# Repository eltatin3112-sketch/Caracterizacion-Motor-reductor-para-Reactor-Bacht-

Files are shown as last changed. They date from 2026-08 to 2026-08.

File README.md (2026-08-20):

# CARACTERIZACIÓN DINÁMICA Y ELÉCTRICA DEL MOTORREDUCTOR (AGITADOR) - GRUPO 5
## Identificación Experimental de Mezcla - Sistemas de Control II (UNET)

Elaborado por: Daniel Torres y Yermey Castro

---

### 1. OBJETIVO DEL PROYECTO DE CARACTERIZACIÓN
Este repositorio contiene todo lo necesario para reproducir la caracterización física de un motorreductor DC utilizado como agitador en un Reactor Batch. 

En la industria, no podemos controlar lo que no conocemos. Por ello, el objetivo de esta práctica es medir cómo responde el motor ante diferentes niveles de potencia (PWM) bajo la resistencia viscosa de 2 Litros de agua. Los datos extraídos permiten identificar no linealidades (como la **Zona Muerta** y la **Saturación**), lo cual es un paso fundamental en *Sistemas de Control II* antes de diseñar un lazo cerrado.

---

### 2. LISTADO DE COMPONENTES UTILIZADOS y Hardware Mínimo Requerido
Para reproducir este experimento, se requiere el siguiente hardware. Todos los componentes deben compartir una referencia de tierra común (GND).

| Componente | Referencia / Modelo | Cantidad | Función en el sistema |
| :--- | :--- | :--- | :--- |
| **Microcontrolador** | ESP32 DevKit V1 (30 pines) | 1 | Procesamiento, conteo de interrupciones y servidor Web WiFi. |
| **Driver de Motor** | Puente H L298N | 1 | Etapa de potencia para suministrar 12V al motor modulados por PWM. |
| **Actuador** | Motorreductor DC tipo TT | 1 | Agitador mecánico del reactor. |
| **Sensor (Feedback)**| Encoder Óptico FC-03 | 1 | Lectura de las ranuras del disco para calcular RPM reales. |
| **Fuente de Poder** | Fuente ATX de PC (Reciclada)| 1 | Suministra 12V estables (Cable amarillo) para la potencia. |
| **Carga de Trabajo** | Jarra plástica + Agua | 1 | Simula la inercia viscosa con 2 Litros de agua. |
| **Aspas** | Fabricadas con alambre y aspas de ventiladores de 12V | 2 | 1 Aspa ligera y 1 Aspa pesada para comparar torque resistente. |

---

### 3. TABLA DE CONEXIONES Y PINOUT (CABLEADO)
Para garantizar el correcto funcionamiento de las señales de control de alta velocidad (PWM e interrupciones del encoder) y mitigar el ruido, se unificaron las referencias de tierra del sistema. Las conexiones del módulo ESP32, el driver de motores y el sensor se estructuran de la siguiente manera:

| Conexión Origen | Señal / Pin | Destino Hardware | Notas Técnicas |
| :--- | :--- | :--- | :--- |
| **Fuente ATX** | `+12V` (Cable Amarillo) | L298N `VCC` | Potencia para el motor TT de 12V |
| **Fuente ATX** | `G
ND` (Cable Negro) | **GND COMÚN** | Unión de tierras del sistema en borne L298N |
| **ESP32** | `3V3` | `VCC` Sensor FC-03 | Alimentación lógica estable de 3.3V |
| **ESP32** | `GND` | **GND COMÚN** | Conectado al pin GND del ESP32 |
| **ESP32** | `GPIO 25` (D25) | L298N `ENA` | Requiere remover el jumper negro de ENA |
| **ESP32** | `GPIO 26` (D26) | L298N `IN1` | Control de sentido de giro del agitador |
| **ESP32** | `GPIO 27` (D27) | L298N `IN2` | Control de sentido de giro del agitador |
| **ESP32** | `GPIO 33` (D33) | `OUT` Sensor FC-03 | Pin con soporte de interrupciones externas |
| **L298N** | `OUT1 / OUT2` | Bornes Motor TT | Conexión directa de potencia al agitador |

#### Conexiones de Advertencia y Seguridad (Pines Strapping):
*   **NO** alimentar el sensor FC-03 con los 5V de la fuente ATX o el pin VIN del ESP32. Su salida de señal debe operar estrictamente a 3.3V para proteger las entradas del ESP32.
*   **OBLIGATORIO:** Conectar físicamente el pin GND del ESP32 con el borne de tierra del L298N para unificar las referencias de las señales lógicas PWM e impedir voltajes flotantes.

*(El diagrama eléctrico detallado en formato .fzz de Fritzing se encuentra dentro de la carpeta `Diagrama electrico` de este repositorio).*

---

### 4. INSTRUCCIONES DE DESARROLLO Y CARGA
Para un estudiante nuevo, siga estos pasos para ejecutar el proyecto:

### A. Preparación del Entorno
1. Descargue este repositorio: Puede hacer clic en el botón verde **"Code" -> "Download ZIP"** y descomprimirlo, o clonarlo vía Git:
   `git clone https://github.com/tu-usuario/tu-repo-motor.git`
2. Instale **Visual Studio Code (VS Code)**.
3. Vaya a las extensiones de VS Code e instale **PlatformIO IDE**.
4. En VS Code, vaya a *File -> Open Folder* y seleccione la carpeta de este proyecto.

### B. Compilación y Carga
*(Nota: Para este proyecto, la página web (HTML/JS) se encuentra embebida directamente en el archivo `main.cpp`, por lo que **no es necesario cargar un sistema de archivos LittleFS**, simplificando el proceso).*
1. Conecte el ESP32 a su computadora vía USB.
2. Abra la terminal de PlatformIO en VS Code y compile el proyecto:
   `pio run`
3. Suba el firmware a la placa:
   `pio run --target upload`

### C. Puesta en Marcha y Monitoreo
1. Una vez cargado, abra el monitor serial en VS Code:
   `pio device monitor --baud 115200`
2. Si el sistema arrancó correctamente, verá el mensaje: `"WiFi Access Point 'Reactor_Batch_G5' Iniciado"`.
3. Desde su teléfono o laptop, busque las redes WiFi y conéctese a **Reactor_Batch_G5** (Contraseña: `control_industrial`).
4. Abra su navegador web (recomendado modo incógnito) e ingrese a: **`http://192.168.4.1`**.
5. Verá la interfaz HMI cargada. Deslice el control PWM y observe cómo el motor gira y las RPM se actualizan.

---

### 5. VALIDACIÓN DE LIBRERÍAS LOCALES (MODO OFFLINE)
Para garantizar el funcionamiento del banco de pruebas en entornos industriales o laboratorios sin acceso a internet (como los de la UNET), las librerías de visualización y exportación se cargan directamente desde la memoria interna del ESP32 (LittleFS).

Al ingresar a la interfaz en tu navegador (`192.168.4.1`), verifique el estado en la sección de diagnóstico:
*   **Chart.js local:** cargado
*   **SheetJS local (XLSX):** cargado
*   **Modo offline:** OK

*Nota:* Si alguna librería aparece como "no cargado", asegúrese de haber ejecutado con éxito el comando `uploadfs` en el Paso 3 de la sección anterior.

---

### 6. PROCEDIMIENTO DEL ENSAYO DE CARACTERIZACIÓN (PASO A PASO)
Este protocolo experimental está diseñado para obtener de forma cuantitativa la fricción, zona muerta, voltaje de saturación, velocidad máxima y corriente de armadura bajo la carga viscosa real de 2 Litros de agua utilizando dos diseños de hélice distintos:

#### Etapa 1: Preparación de la Instrumentación de Medición
1.  **Conexión del Amperímetro:** Conectar un multímetro digital configurado en modo **Amperímetro (mA DC)** en serie con el cable positivo de alimentación que va del driver L298N hacia el motor TT. (Esto nos permitirá medir el consumo de corriente de armadura).
2.  **Conexión del Voltímetro:** Conectar un segundo multímetro configurado en modo **Voltímetro (V DC)** en paralelo a los bornes del motor para validar la linealidad del voltaje suministrado.
3.  **Alineación del Encoder:** Verificar que el disco de 20 ranuras acoplado al eje posterior del motor esté alineado dentro de la herradura del sensor óptico **FC-03** para permitir la lectura digital de RPM en tiempo real sin interferir con la hélice sumergida.

#### Etapa 2: Ensayo con Aspa Ligera (Mezcla Activa de 2 Litros)
1.  Sumergir el agitador con el **Aspa Ligera** dentro de la jarra graduada con exactamente 2 Litros de agua pura.
2.  Abrir la interfaz web del ESP32 en la laptop o teléfono (`192.168.4.1`).
3.  **Rampa Ascendente:** Iniciar en 0 PWM e ir aumentando la velocidad en pasos de 20 unidades (0, 20, 40, 60, 80, 100, etc.) hasta llegar a 255. En cada escalón, esperar exactamente **5 segundos** para que la velocidad se estabilice y anotar en tu hoja de cálculo:
    *   Las **RPM** reales mostradas en la pantalla de telemetría web (leídas por el FC-03).
    *   La **corriente de armadura (mA)** mostrada en el amperímetro en serie.
    *   El **voltaje en bornes (V)** mostrado en el voltímetro en paralelo.
4.  **Rampa Descendente:** Repetir el proceso de forma descendente (de 255 a 0 PWM) en los mismos pasos, anotando los tres valores en cada escalón para cuantificar la histéresis mecánica.
5.  Hacer clic en el botón de la web **"DESCARGAR DATOS EXCEL (CSV)"** para exportar la base de datos de esta prueba.

#### Etapa 3: Ensayo con Aspa Pesada (Mezcla Activa de 2 Litros)
1.  Apagar el sistema, retirar el aspa ligera e instalar el **Aspa Pesada de alambre** en el eje del agitador.
2.  Sumergir el agitador nuevamente en la jarra con los 2 Litros de agua.
3.  Repetir exactamente toda la secuencia de la **Rampa Ascendente y Descendente** (Paso 3 y 4 de la Etapa anterior) anotando las RPM leídas por el encoder, la corriente y el voltaje.
4.  Descargar el segundo archivo de datos CSV para su análisis comparativo en MATLAB.

---

## ⚠️ 7. Problemas Frecuentes (Troubleshooting)

*   **El ESP32 no aparece en el puerto COM:** Instale los drivers CP210x o CH340 según el modelo de su placa ESP32. Asegúrese de usar un cable USB de transferencia de datos, no solo de carga.
*   **El motor zumba pero no gira:** El PWM es demasiado bajo (está en la zona muerta) o la fuente ATX no está encendida (recuerde puentear el cable verde con un negro en la fuente ATX para que encienda).
*   **La página web no carga o se congela:** Desactive los "Datos Móviles" de su teléfono celular mientras está conectado al WiFi del ESP32.
*   **El encoder FC-03 siempre marca 0 RPM:** Revise que el disco de ranuras no esté rozando la herradura negra del sensor. Verifique que el cable verde de datos esté firmemente conectado al pin D33.
*   **El firmware no compila (Error de librerías):** Asegúrese de que el archivo `platformio.ini` esté en la raíz del proyecto y contenga las librerías `ESPAsyncWebServer` y `DallasTemperature`.

---

### 8. INTERPRETACIÓN DE RESULTADOS OBTENIDOS (ANÁLISIS)
A partir del procesamiento de los datos descargados en formato CSV y su análisis en MATLAB, se identificaron los siguientes comportamientos físicos y no linealidades de la etapa de agitación:

#### A. Zona Muerta Mecánica (Fricción Estática)
Se identificó una zona muerta significativa situada entre las **0 y las 25.5 unidades de PWM**. En este rango, aunque el motor recibe un voltaje residual de 0.25V y consume 76 mA de corriente, el torque magnético generado es insuficiente para vencer la fricción interna de los engranajes de plástico y la resistencia viscosa del agua. Para el algoritmo de control, cualquier valor por debajo de este umbral mantendrá el motor estático.

#### B. Eficiencia Eléctrica y Caída de Tensión (Saturación)
A pesar de alimentar el driver L298N con un riel estable de 12V DC de la fuente ATX, el voltaje máximo medido en los bornes del motor a PWM 255 fue de solo **9.25 Voltios**. Esto revela una caída de tensión interna de aproximadamente **2.75V** consumida por la conmutación de los transistores bipolares del puente H, actuando como una saturación física que limita la velocidad máxima de agitación a **441 RPM**.

#### C. Consumo de Corriente de Armadura (Inercia y Fuerza Contraelectromotriz)
La curva de consumo eléctrico registró un comportamiento no lineal típico de motores DC bajo carga viscosa:
*   **Pico de Arranque:** Se registró un pico máximo de corriente de **118 mA** en los niveles medios de PWM (alrededor de 76.5 unidades), punto exacto donde el motor realiza el mayor esfuerzo mecánico para romper la inercia del agua estática.
*   **Efecto de la Fuerza Contraelectromotriz (FCEM):** A medida que la hélice gana velocidad y establece el flujo continuo, la corriente desciende significativamente hasta estabilizarse en los **27.8 mA** a máxima velocidad (441 RPM), demostrando que el sistema es más eficiente a altas velocidades.

#### D. Comparativa de Aspas (Impacto del Diseño Geométrico)
La carga del fluido actúa como una perturbación crítica ligada al diseño de la hélice:
*   **Aspa Ligera:** Permitio alcanzar una velocidad máxima de **405 RPM** bajo carga de 2 Litros.
*   **Aspa Pesada:** Debido a su mayor área de contacto y arrastre viscoso, limitó la velocidad máxima a **320 RPM** bajo las mismas condiciones de potencia. Esto representa una **reducción del 21% en la ganancia de velocidad (Km)**, demostrando que el diseño mecánico influye de forma directa en el torque resistente.

#### E. Análisis Dinámico (Constante de Tiempo Mecánica)
La respuesta temporal al escalón de 0 a 100% de PWM confirmó que la dinámica de la agitación mecánica es sumamente rápida, alcanzando el estado estable en aproximadamente **16 segundos**. Al comparar esto con la constante de tiempo del lazo térmico (92 segundos), se justifica y valida el supuesto de **agitación constante y homogénea** durante todo el posterior proceso de calentamiento PID.

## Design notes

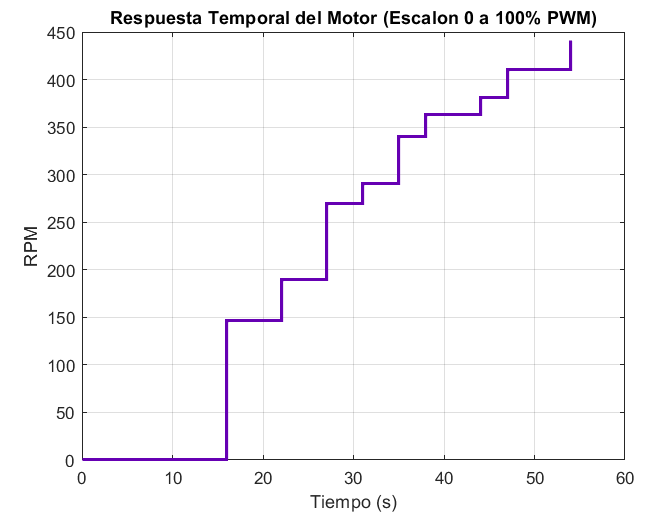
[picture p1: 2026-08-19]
Graficas recreadas con los valores medidos/Grafica de la respuesta escalon de la velocidad del motor con respecto al PWM aplicado .png

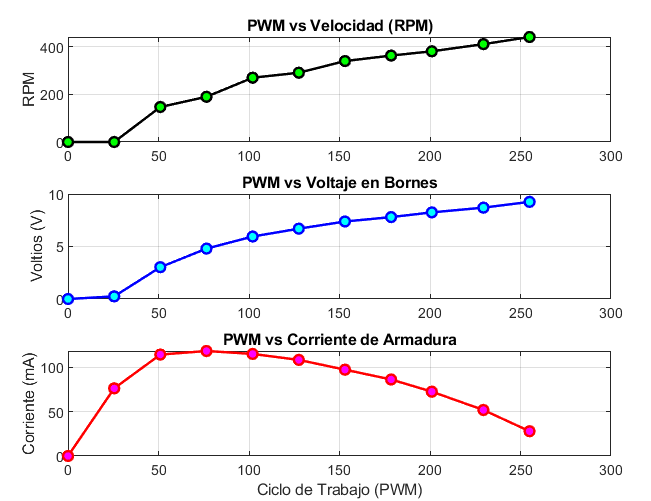
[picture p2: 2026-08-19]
Graficas recreadas con los valores medidos/Grafica de comportamiento de voltaje, corriente y rpm medidos.png

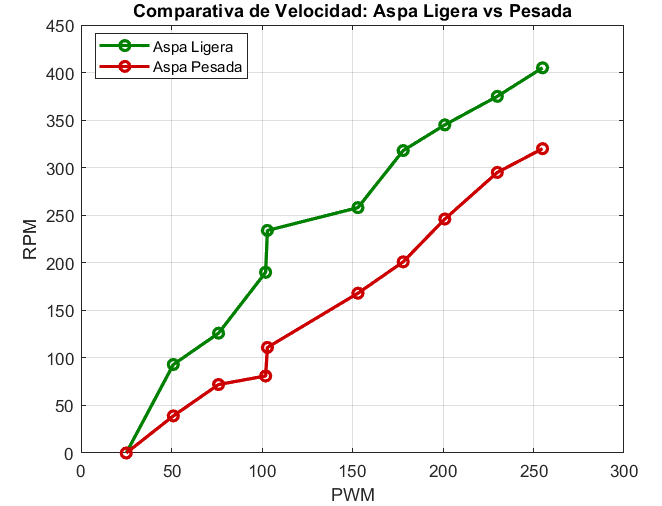
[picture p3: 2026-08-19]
Graficas recreadas con los valores medidos/Grafica de comportamienro de RPM del motor con aspa ligera y pesada.png

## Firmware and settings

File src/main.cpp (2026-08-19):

#include <Arduino.h>
#include <WiFi.h>
#include <ESPAsyncWebServer.h>
#include <OneWire.h>
#include <DallasTemperature.h>

// --- PINES ---
const int PIN_DS18B20 = 4;
const int PIN_ENCODER = 33;
const int PIN_MOTOR_ENA = 25;
const int PIN_MOTOR_IN1 = 26;
const int PIN_MOTOR_IN2 = 27;
const int PIN_SSR = 18;

OneWire oneWire(PIN_DS18B20);
DallasTemperature sensors(&oneWire);
AsyncWebServer server(80);

// Variables de sensores
float temperatura = 0.0;
volatile int pulsos = 0;
int rpm = 0;
int current_pwm = 0;

unsigned long tiempo_anterior = 0;
String log_datos = "Tiempo(s),PWM,RPM,Temperatura(C)\n";
unsigned long inicio_ms = 0;

void IRAM_ATTR contarPulsos() { pulsos++; }

const char index_html[] PROGMEM = R"rawliteral(
<!DOCTYPE HTML><html>
<head>
    <title>Reactor Batch G5</title>
    <meta name="viewport" content="width=device-width, initial-scale=1">
    <script src="https://cdn.jsdelivr.net/npm/chart.js"></script>
    <style>
        body { font-family: sans-serif; background: #1a1a2e; color: white; padding: 20px; text-align: center; }
        .container { display: flex; flex-wrap: wrap; justify-content: center; gap: 15px; }
        .card { background: #16213e; border-radius: 15px; padding: 15px; width: 300px; border: 1px solid #0f3460; }
        .data-val { font-size: 32px; font-weight: bold; color: #00d2ff; }
        .slider { width: 100%; margin: 15px 0; }
        .btn { background: #e94560; color: white; border: none; padding: 10px; border-radius: 5px; cursor: pointer; width: 100%; font-weight: bold; }
        .chart-box { background: white; border-radius: 10px; margin: 15px auto; padding: 10px; max-width: 600px; }
    </style>
</head>
<body>
    <h1>REACTOR BATCH - GRUPO 5</h1>
    <div class="container">
        <div class="card">
            <div>AGITADOR (RPM)</div>
            <div id="rpm_val" class="data-val">0</div>
            <input type="range" min="0" max="255" value="0" class="slider" oninput="updateMotor(this.value)">
            <div>PWM: <span id="pwm_label">0</span></div>
        </div>
        <div class="card">
            <div>TEMPERATURA (C)</div>
            <div id="temp_val" class="data-val">0.0</div>
            <input type="range" min="0" max="100" value="0" class="slider" oninput="updateHeat(this.value)">
            <div>Potencia: <span id="heat_label">0</span>%</div>
        </div>
    </div>
    <div style="margin-top:15px;"><button class="btn" onclick="downloadData()">DESCARGAR DATOS EXCEL (CSV)</button></div>
    
    <div class="chart-box"><canvas id="tempChart"></canvas></div>
    <div class="chart-box"><canvas id="rpmChart"></canvas></div>

    <script>
        function updateMotor(v) { document.getElementById('pwm_label').innerHTML = v; fetch('/set_pwm?v=' + v); }
        function updateHeat(v) { document.getElementById('heat_label').innerHTML = v; fetch('/set_heat?v=' + v); }
        function downloadData() { window.location.href = "/download"; }

        function createChart(id, label, color) {
            return new Chart(document.getElementById(id), {
                type: 'line',
                data: { labels: [], datasets: [{ label: label, borderColor: color, data: [], fill: false }] },
                options: { responsive: true, animation: false }
            });
        }
        var tChart = createChart('tempChart', 'Temperatura (C)', 'red');
        var rChart = createChart('rpmChart', 'Velocidad (RPM)', 'blue');

        setInterval(function() {
            fetch('/data').then(res => res.json()).then(data => {
                document.getElementById('rpm_val').innerHTML = data.rpm;
                document.getElementById('temp_val').innerHTML = data.temp;
                let t = new Date().toLocaleTimeString();
                [tChart, rChart].forEach((c, i) => {
                    c.data.labels.push(t);
                    c.data.datasets[0].data.push(i==0 ? data.temp : data.rpm);
                    if(c.data.labels.length > 30) { c.data.labels.shift(); c.data.datasets[0].data.shift(); }
                    c.update();
                });
            });
        }, 2000);
    </script>
</body>
</html>)rawliteral";

void setup() {
    Serial.begin(115200);
    pinMode(PIN_MOTOR_ENA, OUTPUT); pinMode(PIN_MOTOR_IN1, OUTPUT); pinMode(PIN_MOTOR_IN2, OUTPUT);
    pinMode(PIN_SSR, OUTPUT); pinMode(PIN_ENCODER, INPUT_PULLUP);
    sensors.begin();
    attachInterrupt(digitalPinToInterrupt(PIN_ENCODER), contarPulsos, RISING);
    WiFi.softAP("Reactor_Batch_G5", "control_industrial");
    inicio_ms = millis();

    server.on("/", HTTP_GET, [](AsyncWebServerRequest *request){ request->send_P(200, "text/html", index_html); });
    
    server.on("/set_pwm", HTTP_GET, [](AsyncWebServerRequest *request){
        if (request->hasParam("v")) {
            current_pwm = request->getParam("v")->value().toInt();
            digitalWrite(PIN_MOTOR_IN1, HIGH); digitalWrite(PIN_MOTOR_IN2, LOW);
            analogWrite(PIN_MOTOR_ENA, current_pwm);
        }
        request->send(200, "text/plain", "OK");
    });

    server.on("/set_heat", HTTP_GET, [](AsyncWebServerRequest *request){
        if (request->hasParam("v")) {
            digitalWrite(PIN_SSR, request->getParam("v")->value().toInt() > 0 ? HIGH : LOW);
        }
        request->send(200, "text/plain", "OK");
    });

    server.on("/data", HTTP_GET, [](AsyncWebServerRequest *request){
        request->send(200, "application/json", "{\"temp\":" + String(temperatura) + ",\"rpm\":" + String(rpm) + "}");
    });

    server.on("/download", HTTP_GET, [](AsyncWebServerRequest *request){
        request->send(200, "text/csv", log_datos);
    });

    server.begin();
}

void loop() {
    if (millis() - tiempo_anterior >= 1000) {
        rpm = (pulsos * 60) / 20;
        pulsos = 0;
        sensors.requestTemperatures();
        temperatura = sensors.getTempCByIndex(0);
        
        // Guardar en el LOG para el CSV
        log_datos += String((millis()-inicio_ms)/1000) + "," + String(current_pwm) + "," + String(rpm) + "," + String(temperatura) + "\n";
        
        tiempo_anterior = millis();
    }
}

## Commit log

2026-08-19 Revise README for motor characterization project
    Updated the README to include project objectives, components used, connection details, project structure, development instructions, and experimental procedures for motor characterization.
2026-08-20 Fix image filename case in README.md
